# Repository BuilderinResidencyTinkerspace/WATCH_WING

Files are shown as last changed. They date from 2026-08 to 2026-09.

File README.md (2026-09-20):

# WatchWing - Autonomous Fixed-Wing UAV 

WatchWing is a scratch-built, autonomous fixed-wing UAV . This document
walks through the entire build - airframe, electronics, wiring, and software
configuration — so it can be replicated from scratch.

This is a first-time build, and this README includes the mistakes we made
and what we'd do differently, not just the "correct" path. Read the
**Lessons Learned** section before you start - it will save you real time.

---

## 1. Overview

- **Airframe:** Flite Test "Simple Scout" (stock plan, no custom scaling) - https://www.flitetest.com/articles/ft-simple-scout-build
- **Flight controller:** Pixhawk-class board (Pixhawk 2.4.8 / Pixhawk1) running ArduPilot's **ArduPlane** firmware
- **Ground control:** Mission Planner (Windows)
- **Radio:** FlySky FS-i6 transmitter + FS-iA10B receiver (PPM)
- **Power:** A2212 1400KV motor, SimonK 30A ESC, 3S LiPo battery
- **Navigation:** M10 GPS module with onboard compass (IST8310)
- **Mission logic:** GPS waypoint patrol, flight modes (Manual / FBWA / Loiter)

---

## 2. Full Parts List

| Component | Notes |
|---|---|
| Pixhawk-class flight controller | Pixhawk 2.4.8 or compatible, running ArduPlane |
| GPS + compass module (M10-based) | Two separate connectors: GPS over UART, compass over I2C |
| FS-i6 transmitter | Enable PPM output in transmitter menu |
| FS-iA10B receiver (or FS-iA6B) | Must support PPM output on a single wire |
| A2212 1400KV brushless motor | |
| SimonK 30A ESC | Signal wire connects to Pixhawk, not the battery |
| 3S LiPo battery (we used 3300mAh) | Connects directly to ESC, never to Pixhawk |
| Propeller | Sized to match motor/battery combo |
| SG90 servos ×4 | 2× aileron, 1× elevator, 1× rudder |
| Genuine Depron foam sheet, 5mm | **Do not substitute** — see Lessons Learned |
| Carbon rod or bamboo skewer | Wing spar |
| 3D printed parts | Motor mount/firewall, servo horns, linkage couplers |
| Hot glue gun | Foam assembly |
| Zip ties, tape | Securing the underbody hatch |
| USB cable, laptop | For flashing and Mission Planner |

---

## 3. Airframe — Build to the Flite Test Simple Scout Plan

We initially tried to custom-design our own wing dimensions. **Not preferred** The official Flite Test Simple Scout plan already matches a small
electric motor class well: - https://www.flitetest.com/articles/ft-simple-scout-build

- Wingspan: 952mm
- Wing area: 20.9 dm²
- Target AUW: ~535.8g
- Wing loading: ~25.6 g/dm²
- CG: 62mm (2.44in) back from the wing's leading edge

Download the plan (full-size or tiled, depending on your printer) from
Flite Test's site, print at verified **100% scale** (check the calibration
square before cutting anything), and trace it directly onto your foam.

### Material — genuine Depron

We went through three materials before landing on the right one:

1. **PVC "Sunboard"** — roughly 8x too dense. Do not use.
2. **Thermocol (EPS)** sourced generically — too thick, and cutting it down
   to size with a hot-wire cutter (using a balsa template guide) went badly:
   the balsa scorched, the wire was slightly jagged and produced an uneven
   cut, and the wire itself eventually snapped.
3. **Genuine Depron, pre-cut to 5mm** — this is what actually worked. It
   cuts cleanly with a sharp hobby knife, no hot-wire cutter needed.

If you're sourcing material yourself, ask specifically for **Depron** or
**RC/hobby-grade foam board** by name, not generic "foam board" or "foam
sheet" — those terms commonly return PVC signage board or packaging foam,
neither of which is suitable.

### Assembly

Follow the Flite Test build video/plan instructions for fold pattern, spar
placement, and tail assembly. 
---

## 4. Electronics Wiring

### Power path

```
Battery (3S) ──► ESC power input (thick wires, direct connection)
ESC ──► Motor (thick wires)
ESC's BEC ──► Powers Pixhawk's servo rail (this is what powers the
              servos AND Pixhawk's own logic — battery never
              connects to Pixhawk directly)
```

### Signal wiring — MAIN OUT channel assignments

| Pixhawk MAIN OUT | Connects to | Servo Function |
|---|---|---|
| 1 | Aileron servo (left) | `Aileron` |
| 2 | Elevator servo | `Elevator` |
| 3 | ESC signal wire | `Throttle` |
| 4 | Rudder servo | `Rudder` |
| 5 | Aileron servo (right) | `Aileron2` |

Note: ArduPlane handles the opposite-direction movement between the two
aileron servos automatically once one is set to `Aileron` and the other to
`Aileron2` — no manual reversing needed.

### Receiver

```
FS-iA10B PPM output (single wire) ──► Pixhawk RC IN port
```
Enable PPM output in the transmitter's RX Setup menu before connecting.

### GPS / Compass module

The module has two separate connectors:
- **4-pin connector (GPS, UART)** → Pixhawk's GPS port
- **I2C connector (compass)** → Pixhawk's I2C/compass port

---

## 5. Software Setup (Mission Planner)

### 5.1 Flash ArduPlane

`Setup → Install Firmware → Plane` — select your board and let it flash.
Confirm "Upload Done" before continuing.

### 5.2 Accelerometer Calibration

`Setup → Mandatory Hardware → Accel Calibration` — rotate the board through
all six prompted positions (level, left, right, nose-up, nose-down, upside
down) and hold each steady for a few seconds.

### 5.3 Compass Calibration — important limitation

`Setup → Mandatory Hardware → Compass` — you can calibrate the **internal**
compass on the bench immediately. The **external** compass (on the GPS
module) needs to physically rotate through varied orientations **together
with the Pixhawk as one rigid unit** for the calibration to mean anything.
If they aren't mounted together yet, skip external compass calibration
until they are — you cannot do it properly with the two loose and separate.

### 5.4 Radio Calibration

`Setup → Mandatory Hardware → Radio Calibration` — move every stick and
switch through its full range, then save.

### 5.5 Servo Output — assign functions

`Setup → Servo Output` — assign each channel's function per the table in
Section 4. Confirm live "Position" values change as you move the sticks.

### 5.6 ESC Calibration — use the manual method

Mission Planner's one-click **"Calibrate ESCs"** button is built around
ArduCopter's parameter set and will fail on ArduPlane with a
`"Please ensure your version is AC3.3+"` error. Use the manual method
instead:

1. **Remove the propeller.**
2. Disconnect the battery.
3. Move the throttle stick to full-up, hold it there.
4. Connect the battery — the ESC beeps to confirm it registered max throttle.
5. Move the throttle stick to full-down.
6. The ESC beeps again, confirming the minimum.
7. Disconnect and reconnect the battery normally.

### 5.7 Arming — the most common "nothing responds" cause

If your control surfaces move but the **motor won't respond to throttle at
all**, this is very likely **not** a wiring or configuration problem —
ArduPilot blocks all throttle output while disarmed, full stop. Check the
Messages/pre-arm list for what's actually failing (commonly an incomplete
compass calibration). Once pre-arm checks clear and the board is armed
(via the rudder-arm gesture, or Mission Planner's Actions tab), throttle
will respond immediately.

### 5.8 Custom AHRS Orientation (if mounting Pixhawk at an angle)

If your Pixhawk isn't mounted flat (ours was mounted on a side wall,
requiring Roll 90° + Yaw 180°), and the exact combination you need isn't in
the standard `AHRS_ORIENTATION` dropdown:

1. Set `AHRS_ORIENTATION` to **Custom1**.
2. Set `CUST_ROT_ENABLE = 1`.
3. Enter your actual mounting angles into `CUST_ROT1_ROLL`, `CUST_ROT1_PITCH`,
   `CUST_ROT1_YAW`.
4. Write, reboot, and verify the artificial horizon responds correctly to
   the board's real physical attitude.

### 5.9 Flight Modes

`Config → Flight Modes` — assign a spare channel (we used Channel 5) as
your mode switch (`FLTMODE_CH`). We used a 3-position switch mapped as:

- Position 1: **Manual**
- Position 2: **FBWA** (fly-by-wire — holds a target bank/pitch angle,
  meaningfully more forgiving than Manual for a first-time pilot)
- Position 3: **Loiter** (circles a fixed GPS point)

---

## 6. Mounting Into the Airframe

- Mount servos into the wings/tail using 3D-printed servo horns; connect
  with bent-wire pushrods.
- Calculate CG before placing the battery; secure it with double-sided tape.
- Mount the Pixhawk (note its orientation — see Section 5.8 if not flat).
- Mount the receiver inside the body.
- Leave the GPS module **exposed to the sky** — it needs a clear view for
  satellite lock and cannot be enclosed like the other electronics.
- 3D-print and glue a firewall at the nose for the motor mount. (given in cad section)
- Close the underside hatch with tape and zip ties.

Once the Pixhawk and GPS are mounted together on the airframe, go back and
complete the **external compass calibration** (Section 5.3) — this is the
point where it finally becomes possible.

---

## 7. Before Your First Flight

- **Practice on a simulator first.** We used [PicaSim](https://www.thepicasim.com/)
  (free). This is not optional — get real stick time before risking the
  airframe.
- **Physically verify every control surface's direction** against stick
  input before flying. A reversed elevator caused one of our crashes.
- **Double-check your flight mode switch positions** — know exactly which
  physical position corresponds to which mode, and rehearse switching
  between them without looking, before you're relying on it mid-flight.
- Remove the propeller for all bench/arming tests until you're actually
  ready to fly.
- Scout your flight location for obstacles (trees, power lines, buildings)
  before taking off.

---

## 8. Lessons Learned

- **Material sourcing is the single biggest time sink in this build.** Ask
  for Depron/EPP by name; verify density by weighing a sample before
  committing to a full sheet.
- **"Servo works, motor doesn't" is almost always an arming/pre-arm issue**,
  not a wiring problem. Check the Messages tab before assuming anything
  else is wrong.
- **Mission Planner's automated ESC calibration doesn't work for
  ArduPlane** — use the manual method from the start.
- **External compass calibration requires the GPS and Pixhawk to be
  mounted together** — don't attempt it while they're loose on a bench.
- **FBWA is a better default flying mode than pure Manual** for a
  first-time pilot — it limits how far the plane can bank/pitch, which
  meaningfully reduces stall risk during panicked, tight corrections.
- **Flight mode switch mix-ups are a real, common failure mode** — an
  accidental Loiter engagement mid-flight caused one of our crashes.
  Rehearse switch positions on the ground before trusting them in the air.
- **A broken firewall in a crash is often a good outcome, not a bad one** —
  so while 3d printing, give it low infill. it absorbed impact energy that would otherwise have gone into the motor
  or fuselage.

---

## 9. Status

WatchWing achieved three powered manual test flights.. The airframe was damaged beyond repair on the
third crash.

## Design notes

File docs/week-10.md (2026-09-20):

# Week 10

Do more flight tests

## What we did

After the first crash, the firewall had broken - which we think was actually a good thing, since if it hadn't, that force wouldn't have been absorbed, and the damage would likely have been much worse. We then spent more time on the PicaSim flight simulator to build up more experience flying before trying again. We corrected the elevator direction properly and made sure all the controls were mapped in the right order this time.

We then took it out to the ground and flew it. It did fly, until it seemed headed straight for a powerline, and in that moment I panicked and banked the plane sharply to the left, which sent it crashing straight down. 

https://github.com/user-attachments/assets/e85e026e-feed-42d0-a233-7aa0a86a7abd

There was some heavy damage, but we taped it up and somehow got it holding together again - though it didn't look like it could survive one more crash.

So we decided to make use of the GPS functionality as well, particularly Loiter mode, which makes the plane circle around a fixed point. While configuring the GPS, we came across the different flight modes available and realized there was an FBWA option - fly-by-wire stabilization - something we'd missed entirely earlier, and that might have given us better control and possibly avoided the earlier crashes altogether. On the transmitter, we mapped channel 5's topmost switch position to Manual, the middle position to FBWA, and the lowest position to Loiter. We then found a bigger, more open ground to give ourselves a smoother flying experience.

We flew it in Manual mode first, and the plane was climbing higher than expected when I tried switching it to FBWA - but I think the switch accidentally went one position too far, into Loiter instead. Around the same time, I also pulled the throttle down, whether out of instinct or in reaction to how fast it was climbing, it's honestly hard to say in hindsight. Between the mode ending up on Loiter and the throttle being cut, the plane went down and crashed straight into a powerline, damaging the body beyond repair.

https://github.com/user-attachments/assets/d0688072-a5b2-436c-84c3-b29f3b602719

https://github.com/user-attachments/assets/42bfe03f-b019-4237-b2a9-4cf66adad5d7

We didn't get the clean finish we were hoping for. But we did learn a lot, so not completely feeling bad I suppose. But yeah, that was the end of it.

## Problems and blockers

-

## Decisions

-

## Next week

-

## Links

- Code:
- Photos / CAD:

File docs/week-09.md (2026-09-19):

# Week 9

**Goal this week:**
Mount all the electronics into the body, get everything wired and confirmed working, and take it up for a first flight

## What we did
We started mounting the components inside the body of the plane. First, we mounted the servos for both ailerons, the elevator, and the rudder. The hardest part here was bending the rods correctly to connect each servo to its control surface — for this, we 3D-printed servo horns so the rods could actually connect properly at both ends.

We then placed the battery, working out the center of gravity of the plane first, and mounted it in position using double-sided tape. The Pixhawk was mounted onto the side wall, and the radio receiver was placed inside the body as well. The GPS was kept exposed, using a gap we'd already left for it during the design stage. We also designed a firewall for mounting the motor, 3D-printed it, and fixed it to the front of the body using a glue gun.

WhatsApp Image 2026-09-19 at 19 44 54

Once all of that was in place, we made all the connections and started checking everything. The servos and motor were working fine, but we ran into an orientation issue — since the Pixhawk was mounted on the side wall rather than flat, we worked out that the correct orientation needed to be set as Yaw 180 and Roll 90. There was no preset option for this exact combination, so we had to figure out how to set up a custom orientation instead, which sorted the issue out.

https://github.com/user-attachments/assets/c18ed667-0398-4f2e-9c53-f4187ca28d09

After that came the bigger task of closing up the underside of the plane. We closed it using tape and added zip ties for extra security. We (Shan chettan lol)then checked the motor's thrust by arming it, and it gave a good amount of thrust, which had us fairly excited.

https://github.com/user-attachments/assets/7c95ffb8-d15e-42a9-8387-aaaa71229296

Looking back, that excitement is exactly where we went wrong — we went straight into our first flight attempt without simulating beforehand or properly checking the plane's control response first. In particular, we hadn't verified the elevator's orientation — pushing the stick down should have raised the elevator, but the direction was actually reversed. As soon as we moved the stick down in flight, the plane reacted the wrong way and crashed. The damage from this included a broken propeller and small cracks in the body.

https://github.com/user-attachments/assets/8a103069-e0ae-4b2f-8837-02de886d7a3d

-

## Problems and blockers

-

## Decisions

Fix the body and make subsequent flights

-

## Next week

-

## Links

- Code:
- Photos / CAD:

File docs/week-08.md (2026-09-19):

# Week 8

-Get the Pixhawk actually talking to the servos and motor correctly, and work through ArduPilot's setup and calibration process cleanly enough to start real bench testing, before anything gets mounted into the body.

## What we did

So initially, what we did was read through the ArduPilot documentation to get a basic understanding of how everything fit together. We then uploaded the ArduPlane firmware onto the Pixhawk using Mission Planner's ground control software. After that, we went through the basic configuration steps — accelerometer and compass calibration — though only the internal compass could actually be calibrated, not the external one that comes with the GPS module. What we've come to understand is that in order to calibrate the external compass, it needs to be moved around together with the Pixhawk, both mounted on a single fixed unit, so we decided to leave that calibration for after both were attached to the main body.

We then moved on to radio calibration, and from there to the servo output section. The Pixhawk was powered through a 3300mAh 3S LiPo battery connected to the ESC, which was then wired into MAIN OUT channel 3, and that in turn powers the board. The remaining four servos were attached across the rest of channels 1 to 5.

https://github.com/user-attachments/assets/d9e56841-344a-40bb-9b3b-cab85152925d

In the Servo Output screen, all the servos moved correctly in response to radio input, except for throttle on channel 3. We went through pretty much every component individually to try and find the cause. We checked the RCMAP parameters — RCMAP_ROLL, RCMAP_PITCH, RCMAP_THROTTLE, RCMAP_YAW — and they were all sitting at their correct default values. We checked the servo function assignment again and confirmed channel 3 really was set to Throttle. We checked the physical wiring, checked that the receiver's channel order matched what Pixhawk expected, and confirmed on the transmitter's own screen that the throttle stick's output value was genuinely changing when we moved it, so the signal was leaving the transmitter correctly. It also showed up correctly in the radio calibration screen. This told us the input signal was being sent correctly, it just wasn't translating to an actual output. We decided to set that issue aside for the moment and moved on to ESC calibration.

https://github.com/user-attachments/assets/6a6e90e5-7b14-45b2-b108-5be83ae9cdb1

We tried Mission Planner's one-click "Calibrate ESCs" button, and it failed outright with an error saying to make sure our version was "AC3.3+." After looking into it, it seems this automated calibration flow is really built around ArduCopter's parameter set rather than ArduPlane, which is probably why it didn't work cleanly for a fixed-wing setup like ours. We switched to the manual ESC calibration method instead — throttle stick held all the way up, connect the battery, wait for the ESC to beep confirming it caught the top of the range, then throttle down to get the bottom of the range confirmed the same way. That part worked fine.

The actual explanation for the frozen throttle turned out to be arming, not anything wrong with the wiring or configuration at all. ArduPilot simply will not let throttle output do anything while the board is disarmed, and our pre-arm checks were failing — as far as we can tell, this was tied to the compass not being fully calibrated yet. Once we forcefully armed it through the Actions tab on the Data page in Mission Planner, we were able to get an actual output signal from throttle on channel 3.

## Problems and blockers

-

## Decisions

-

## Next week
Attach the components to the main body

-

## Links

- Code:
- Photos / CAD:

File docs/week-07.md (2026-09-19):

# Week 7

**Goal this week:** Get the Depron sheet, finalize the airframe design, and complete the main body of the UAV.

## What we did

This week, the **Depron sheet finally arrived**. It was pre-cut to  **5 mm thickness**, which was exactly the type of material we had been looking for during the previous weeks. After all the problems we had faced with Sunboard and Thermocol, getting the correct material was a major step forward for the project.

With the material finally available, we decided to simplify our approach to the airframe design. Instead of continuing to derive our own wing span and chord dimensions, we decided to build the **Flite Test Simple Scout** according to its official plan. Its published specifications were already quite close to what we needed for Watchwing. The design has a **952 mm wingspan** and a wing area of approximately **20.9 dm²**, with a published dry weight of around **425.2 g** and an all-up weight of approximately **535.8 g**. Its wing loading is around **25.6 g/dm²**, which was comfortably within the range we were looking for.

We also compared the Simple Scout with another Flite Test design, the **Simple Storch**, to see if it would be a better option for carrying our electronics and camera system. However, the Simple Storch had a much larger wingspan of approximately **1460 mm** and an all-up weight of around **1005 g**. This put it into a significantly larger and heavier class than what we had originally sized our **A2212 1400KV motor** and the rest of our system for. The Simple Scout therefore fit our requirements much better.

We also checked the Scout's expected weight against our motor. Our **A2212 1400KV motor** can produce approximately **900 g of thrust**, which gives a thrust-to-weight ratio of roughly **1.68:1** at the Scout's published all-up weight. This gives us a comfortable amount of available thrust while still leaving some capacity for the additional electronics we need to carry, including the **Pixhawk, GPS, and Raspberry Pi Camera**.

Once the design was finalized, we started constructing the actual airframe. We traced the different components directly from the printed **Simple Scout plans** and began cutting the Depron for the **wings, fuselage, and tail**. This was the first time we were able to properly proceed with the airframe using the material and design we had settled on.

The timing of the build coincided with **Onam**, which meant that a significant portion of the week was taken up by family time, travel, and festival activities. Because of this, we did not have the same amount of continuous hands-on working time that we normally would. Instead, the construction had to be done in shorter periods whenever we had the opportunity.

Even with the limited working hours, we were able to make good use of the time available and successfully complete the **main body of the UAV** during the Onam period. After the delays and failed material experiments from the previous weeks, finally having a completed airframe was a significant milestone for the project.

## Problems and blockers

The main limitation this week was the **Onam vacation**, which reduced the amount of time we could spend working on the UAV. Instead of having several uninterrupted days for construction, the work had to be done in shorter sessions between travel, family commitments, and other festival activities.

Despite this, we were still able to complete the main airframe within the available time.

## Decisions

After comparing the available options, we finalized the **stock Flite Test Simple Scout** as our airframe. We decided to build it according to the official plan without custom scaling, since its dimensions, weight, and wing loading were already well suited to our requirements.

We also ruled out the **Simple Storch** because its larger wingspan and significantly higher all-up weight would have placed it in a heavier aircraft class than what our existing motor and electronics payload were designed around.

## Next week

Next week, we will continue working on the **electronics bring-up** in parallel with the completed airframe. We will begin bench-testing the **RC transmitter, receiver, ESC, motor, and servos** to make sure the individual components are functioning correctly.

We will also start planning the modifications required inside the **fuselage and electronics bay** to accommodate the **Pixhawk, GPS, Raspberry Pi, and camera system**, while keeping the components secure and maintaining a suitable centre of gravity for the aircraft.




- Code:
- Photos / CAD:

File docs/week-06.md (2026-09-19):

# Week 6

**Goal this week:**

## What we did

nothing much, got busy with coursework and exams

## Problems and blockers

-

## Decisions

-

## Next week

-

## Links

- Code:
- Photos / CAD:

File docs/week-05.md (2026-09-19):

# Week 5

**Goal this week:** Get a suitable body material sorted out and make progress on the airframe while starting the electronics work in parallel.

## What we did

This week, we finally found a source for **Thermocol** nearby. Interestingly, we found it at a medical store and were able to get medicine boxes made of thermocol to continue working on the airframe. However, when we brought it back and checked the dimensions, we realized that the sheet was much thicker than what we actually needed for the wings.

We decided to try reducing the thickness ourselves using the **hot-wire cutter** we had built earlier. To keep the cut level and consistent, we planned to use a **balsa wood template** clamped on either side of the Thermocol and guide the hot wire along the templates. This seemed like a simple solution, but when we actually tried it, we ran into another unexpected problem. The hot wire remained in contact with the balsa template for too long in some places, causing the wood to **scorch and burn**.

The cutting itself also did not turn out as expected. The wire we were using still had some **jagged sections** left over from the earlier problems with the cutter, and this caused the Thermocol to come out with an uneven and rough surface instead of the clean, flat surface we needed for the wing.

Things became even more difficult when the **gear cable wire** we had been using as a substitute for nichrome wire finally snapped during the process. Since we did not have a replacement wire available, we could not continue experimenting with the cutter. At this point, with the balsa template getting damaged, the Thermocol cuts coming out uneven, and the cutting wire broken, it became clear that we were spending too much time trying to make the material and cutting setup work.

After considering the options, we decided that continuing with Thermocol was no longer practical. We therefore decided to **order genuine Depron sheet** instead. Although it would take approximately a week to arrive, using the correct material would save us from repeatedly trying to modify an unsuitable material and would give us a much better starting point for the final airframe.

Rather than letting the week of waiting become completely unproductive, we decided to start working on the **electronics in parallel**. This would allow us to continue making progress on the project while waiting for the Depron.

We also made an important change to the camera system this week. Based on **Shan chettan's advice**, we decided to replace the **ESP32-CAM with a Raspberry Pi Camera**. Since the Watchwing project depends heavily on comparing images from different flights, image quality is particularly important. The Raspberry Pi Camera provides advantages in areas such as **resolution, low-light performance, and autofocus**, making it a more suitable option for the image-comparison part of the project. We decided that making this change now would be much easier than building more of the system around the ESP32-CAM and changing it later.

## Problems and blockers

The main problem this week was that the Thermocol we sourced was **too thick**, and our attempt to reduce its thickness using the hot-wire cutter did not work as planned. The balsa templates began to burn when the hot wire remained against them for too long, while the uneven sections of the cutting wire resulted in rough and inconsistent cuts.

The situation became more difficult when the **gear cable wire snapped** during the process. Since we did not have a spare wire available, we were unable to continue testing the cutter.

After several attempts, it became clear that trying to fix the existing setup further would take more time without guaranteeing a usable wing. We therefore decided to move to genuine Depron instead.

The Depron would take around **one week to arrive**, which meant that airframe construction would have to pause temporarily. However, we decided to use this waiting period to begin the electronics work rather than leaving the project idle.

## Decisions

After the failed Thermocol cutting attempts, we decided to **abandon Thermocol as the body material** and order genuine **Depron sheet** instead. Although this meant waiting approximately a week for the material to arrive, we felt that using the correct material would be more reliable than continuing to modify the Thermocol ourselves.

We also decided to begin **electronics bring-up in parallel** while waiting for the Depron. This would allow us to work on the electrical and control systems independently of the physical airframe.

Another important decision was to switch the camera system from the **ESP32-CAM to a Raspberry Pi Camera**, following Shan chettan's advice. Since image quality will directly affect the round-to-round change-detection process, we decided that the better image quality and camera capabilities were worth making the change at this stage.

## Next week

Next week, we will begin the **Raspberry Pi bring-up**, starting with flashing the operating system, setting up headless SSH access, installing `picamera2`, and testing image capture.

At the same time, we will begin **bench-testing the RC transmitter, receiver, ESC, motor, and servos as a standalone system**, without connecting them to the flight controller initially. This will allow us to verify each part of the control and propulsion system before integrating everything into the UAV.

## Links
- Code:
- Photos / CAD:

https://github.com/user-attachments/assets/4cb5d6a5-31f4-4e36-bd63-a17d4b966aa3

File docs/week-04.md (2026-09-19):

# Week 4

**Goal this week:** Get a suitable body material and a reliable cutting method ready so that construction of the UAV airframe could finally proceed.

## What we did

This week, we focused mainly on finding a suitable material for the UAV body and figuring out a practical way to cut the airfoil and body components. We first tested **Sunboard (PVC foam)**, which we had previously used, but rejected it because it was too thick and dense for our aircraft and would add too much weight to the final airframe.

We then tried **Styrofoam (EPS)** as another possible material. Although it was lightweight, we found that it was not firm enough for our requirements. When we tried cutting it with a blade, the material crumbled easily and did not maintain enough rigidity, making it unsuitable for building the airframe.

After testing the different materials, we decided to use **Thermocol (low-density EPS)** instead. It was considerably lighter while still providing enough rigidity for the structure. However, we quickly realized that cutting it accurately with a normal blade would be difficult, so we decided to use a **hot-wire cutter** instead.

We finalized the CAD design for the **Clark-Y airfoil** and exported the required STL file to create the cutting template. Since a proper nichrome wire was not available locally, we decided to experiment with **gear cable wire** as a substitute. We then built our own DIY hot-wire foam cutter from scratch using the available materials.

Before trying to cut the actual foam, we connected the cutter to a variable DC power supply and tested it at around **16 V and 3.5 A**. The wire heated up properly, confirming that the basic setup was working. However, the wire initially had problems with sagging and kinking. We solved these issues by re-tensioning the wire and manually straightening it instead of replacing it.

By the end of the week, the material and cutting setup were finally ready. We had not yet started cutting the actual Thermocol body panels, but the hot-wire cutter had been successfully bench-tested and was ready for the next stage of construction.

## Problems and blockers

One of the biggest problems we faced was the unavailability of **Depron**, which was our originally intended body material. Due to the ongoing war affecting its supply, we were unable to source it locally and had to look for alternative materials.

We also could not find proper **nichrome wire** locally for the hot-wire cutter. Because of this, we decided to experiment with gear cable wire as a substitute. Although it worked during the initial test, we still need to determine whether it will be durable enough for repeated cutting.

Another issue we faced was that the cutter wire initially **sagged and had some natural kinks**, which could have affected the accuracy of the airfoil cuts. We managed to correct this by re-tensioning the wire and manually straightening it.

The actual Thermocol cutting had also not started yet, so the performance of the cutter on the real material was still something we needed to verify.

## Decisions

After testing the available materials, we decided to use **Thermocol (EPS)** as the main body material for the UAV.

We also finalized the **Clark-Y airfoil** for the wing and completed the CAD/STL template that would be used with the hot-wire cutter.

Since proper nichrome wire was not available, we decided to continue using **gear cable wire as a temporary substitute**, unless we were able to find a reliable source of nichrome wire.

With the material, airfoil design, and cutting method decided, we were finally ready to start constructing the actual airframe.

## Next week

Next week, we will complete the **body of the UAV**, including the wings, fuselage, and tail, using the Thermocol and the hot-wire cutting setup. Once the panels are completed, we will weigh the finished airframe and check the actual weight against our target **AUW and wing loading**.

After completing the main body, we will also start working on the **electronics**, including the flight controller, servos, motor, ESC, GPS, and other components required for the UAV.

## Links
- Code:
- Photos / CAD: WhatsApp Image 2026-08-09 at 08 46 01

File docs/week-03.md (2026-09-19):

# Week 3

**Goal this week:** Build the airframe of the UAV, including the wings, fuselage, and tail, using foam board.

## What we did

This week, we started building the physical airframe of the Watchwing UAV. We began with the wings and spent around three days cutting and assembling the wing panels. Once the wings were completed, we weighed them and found that the complete wing set weighed around **300 g**, while the total wing area was approximately **1250 cm²**.

We then compared these values with the design targets we had calculated earlier. When we checked the expected component weight and the approximately **900 g of motor thrust** available from our selected motor, we realized that both the wing area and the wing weight were significantly different from what we needed. This made us go back and check our calculations as well as the material that we had used to build the wings.

While investigating the problem, we discovered that we had made a material mistake. The foam board we had purchased was actually **PVC foam board, commonly called Sunboard**, which is mainly used locally for making signs and hoardings. We had assumed that it was similar to the lightweight hobby foam used for RC aircraft, such as **Depron or EPP**, but it was much heavier. From the finished wing itself, we calculated an areal density of approximately **0.24 g/cm²**, which is around eight times heavier than true Depron of a similar thickness. This explained why our wing had become so heavy.

We also cross-checked our design with a published reference aircraft using a similar **2212 motor class**. The reference aircraft was around **640 mm long**, had an approximately **810 mm wingspan**, a flight weight of around **495 g**, and used a four-channel, four-servo control setup. This comparison helped us confirm that our selected motor and servo configuration were reasonable, and that the main problem was with our wing sizing and construction material rather than the basic component selection.

After identifying the problem, we went back to the calculations and redesigned the wing from the beginning. We decided on a **950 mm wingspan** and targeted a wing loading of approximately **40 g/dm²**. We chose this value as a reasonable middle ground: it would keep the aircraft relatively light and simple to build while still providing a comfortable safety margin compared with higher wing loadings.

We then calculated the required wing area assuming a target total aircraft weight of around **600 g**. At a wing loading of 40 g/dm², we would need approximately **1500 cm² of wing area**. With a wingspan of 950 mm, this gives a chord of roughly **16 cm**. At this weight range, our existing motor would provide a thrust-to-weight ratio of approximately **1.5**, giving us a good amount of available thrust.

## Problems and blockers

The biggest problem we encountered this week was that our first wing design turned out to be both **too small and too heavy**. The wing had an area of only around **1250 cm²** while weighing approximately **300 g**. The main reason for this was the incorrect material we had used.

With the original wing dimensions and material, the calculated wing loading was approximately **84.6 g/dm²**, which was much higher than our desired range. The estimated stall speed was also around **50 km/h**, which was too high for the type of aircraft we were trying to build.

Another problem was that the term **"foam board"** turned out to be quite ambiguous when sourcing the material locally. PVC foam sheets used for signage and lightweight hobby foams such as Depron or EPP can be sold under similar descriptions, even though their densities are very different. Because of this, we ended up purchasing the wrong material for the aircraft.

## Decisions

After going through the calculations and identifying the material problem, we decided to completely **rebuild the wings** rather than trying to extend or modify the existing ones. This time, we will source proper **Depron or suitable EPP foam** before starting the new build.

We finalized the main structural targets for the new wing. The wingspan will be **950 mm**, with a chord of approximately **16 cm**, giving us a total wing area of around **1500 cm²**. We are targeting a wing loading of approximately **40 g/dm²** and using **600 g as the estimated all-up weight**, giving us some additional safety margin over the bare component weight. At this loading, the estimated stall speed is approximately **34.5 km/h**, which is considerably lower than our original design.

We also decided to rebuild the tail surfaces according to the new wing size. The horizontal stabilizer will be approximately **220–300 cm²**, while the vertical fin and rudder will be approximately **130–150 cm²**. The fuselage length can remain relatively close to the original design, around **640–680 mm**, since our main sizing problem was with the wing rather than the fuselage.

Before purchasing the new foam, we also decided to verify the material properly. We will check the cross-section of the foam and weigh a sample piece to estimate its density before buying an entire sheet. This should prevent us from repeating the same material mistake.

## Next week

Next week, we will source the correct **Depron/EPP foam** and begin rebuilding the wings, fuselage, and tail using the new dimensions. The new wings will be cut to a **950 mm span and approximately 16 cm chord**, while the horizontal stabilizer and vertical fin/rudder will be resized according to the new wing area.

Once the new airframe is assembled, we will weigh the complete aircraft and check whether the actual weight is close to our **600 g target**. We will then recalculate the actual wing loading and thrust-to-weight ratio using the measured weight before moving forward with the rest of the UAV build.

## Links

- **Reference for build:** (https://www.youtube.com/watch?v=LzZ4Oqk_J1Y)
- **Photos:** 
- Photos : 
-
  
  


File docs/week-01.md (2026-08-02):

# Week 1

**Goal this week:**
Get oriented — understand the BIR program structure and meet the team.

## What we did
- Sat in a circle for an introductory briefing on the project and program expectations
- Talk by Sidharth on open source projects - what they are, why they matter, and how to contribute to/use them responsibly
- Discussed overall direction for the Watchwing UAV project at a high level

## Problems and blockers
- None yet — orientation week

## Decisions
- Project name settled: Watchwing
- General scope confirmed: autonomous waypoint-guided fixed-wing UAV using ArduPilot

## Next week
- Prepare and deliver formal project presentation
- Start narrowing down system architecture (flight controller, sensors, firmware choice)

## Links

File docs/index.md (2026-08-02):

# Project Name

One line on what you're building.

**Team:** Name, Name
**Program:** Builder-in-Residence

## The problem

What breaks, for whom, and how often.

## The idea

How you solve it, and what makes your approach different.

## Hardware and tools

- Boards / sensors:
- Other tools:

## Repo layout

- `docs/` — this site: overview and weekly logs
- `code/` — firmware, scripts, anything runnable
- `cad/` — 3D models and design files

## Weekly logs

Start with [Week 1](week-01.md) and fill one in each week.

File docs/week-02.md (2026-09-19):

# Week 2

**Goal this week:** Formally present the Watchwing project to the group and finalize the technical direction.

## What we did

This week, we formally presented the **Watchwing project** to the group. We explained the main goals of the project, its scope, and the overall architecture that we were planning to use. We also presented the concept of the autonomous UAV, which is a fixed-wing drone designed to fly through a predefined route using a set of GPS waypoints.

We explained how the main **change-detection system** would work. The UAV will first fly through a fixed route containing a number of GPS waypoints, for example, five points. At each waypoint, the camera will be triggered using GPS to capture an image. We called this first set of images **Round A**. After some time, the UAV will fly the same route again and capture images at the same five waypoints, which we called **Round B**. The images from both flights will then be compared with each other, such as Point 1 from Round A with Point 1 from Round B, Point 2 with Point 2, and so on. If a significant difference is found between two corresponding images, that area can be flagged as a possible change.

We also discussed the different components that would be required to make the system work. The planned system would use a **Pixhawk flight controller** running **ArduPilot's ArduPlane firmware**, along with GPS and IMU sensors for navigation and orientation. We planned to use **Mission Planner** as the ground-control software, with **MAVLink** being used for communication between the ground station and the UAV.

During the discussion, we also decided to record a **continuous video throughout the entire flight**. This video would be saved onto an onboard SD card so that the complete flight could be manually inspected later if required. This would give us an additional source of information apart from the individual images captured at the waypoints.

However, while discussing the system in more detail, we came across a few problems that needed to be solved. We were still unsure about which specific flight controller hardware would be the most suitable for our UAV. Another important problem was figuring out how accurately the UAV could return to the exact same position and orientation at each waypoint during different flights. Since our change-detection method depends on comparing images taken from the same locations, even a small difference in the position or orientation of the UAV could affect the accuracy of the image comparison.

After discussing these issues, we finalized the basic approach for the change-detection system. We decided to use **GPS-triggered images captured at fixed waypoints** and compare the corresponding images from different flight rounds. Along with this, we would maintain a continuous video recording of the flight on the onboard SD card for manual inspection. With the basic technical direction decided, we were ready to move on to the physical construction of the UAV.

## Problems and blockers

One of the main problems we faced this week was deciding between the different **flight controller hardware options**. We also needed to understand how accurately the UAV could return to the same position and maintain the same orientation at each waypoint during repeated flights. This is important because the images captured during different rounds need to be sufficiently similar in terms of viewpoint for the change-detection system to work reliably.

## Decisions

We decided to use a **GPS-triggered image capture system**, where the UAV captures images at predefined waypoints during each flight. The images from different rounds will then be compared point-to-point to identify possible changes in the monitored area. We also decided to record a **continuous video of the entire flight** and store it on the onboard SD card so that the flight can be manually reviewed whenever necessary.

## Next week
Start with the body of UAV

Next week, we will start working on the **body of the UAV**. We will begin developing the physical airframe of the fixed-wing aircraft and work on the initial design and construction.

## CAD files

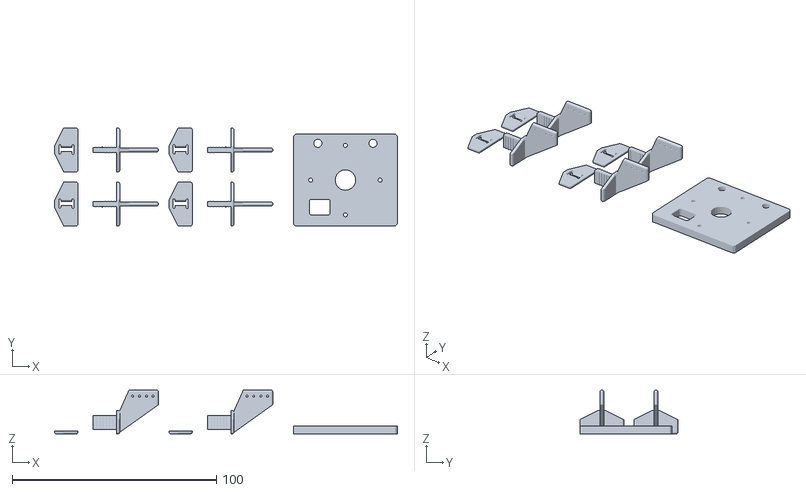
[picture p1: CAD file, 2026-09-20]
cad/print_batch_4horns_1firewall.stl
167.9 x 48.0 x 21.5

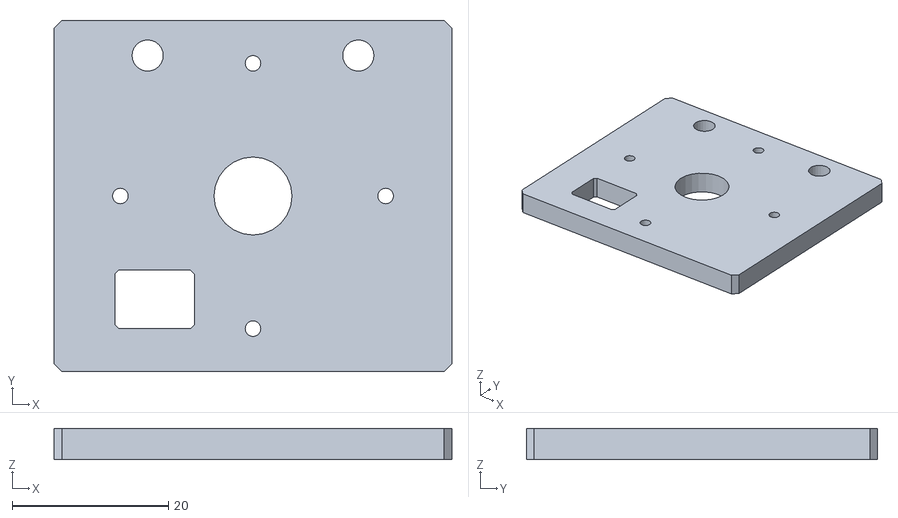
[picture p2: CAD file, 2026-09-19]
cad/rc-firewall (1).stl
51.0 x 45.0 x 4.00

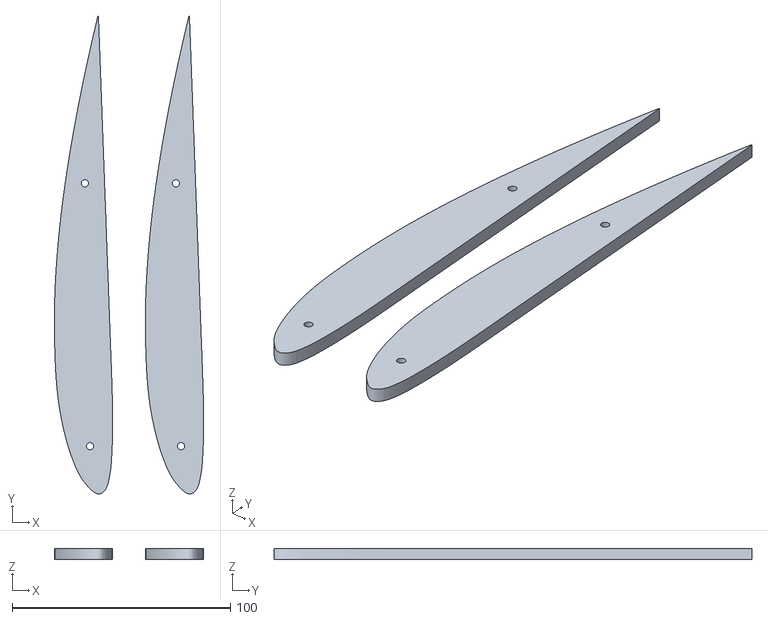
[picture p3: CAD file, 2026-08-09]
cad/clarky_template_5mm_selftap (1).stl
68.4 x 219.0 x 5.00
